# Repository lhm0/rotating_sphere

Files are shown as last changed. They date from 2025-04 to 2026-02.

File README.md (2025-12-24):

# Rotating LED Sphere – RP2040 POV Display
**UPDATE December 24th, 2025**
I have made a change to the header of the motor in order to make the connection to the sphere stronger and long term stable.

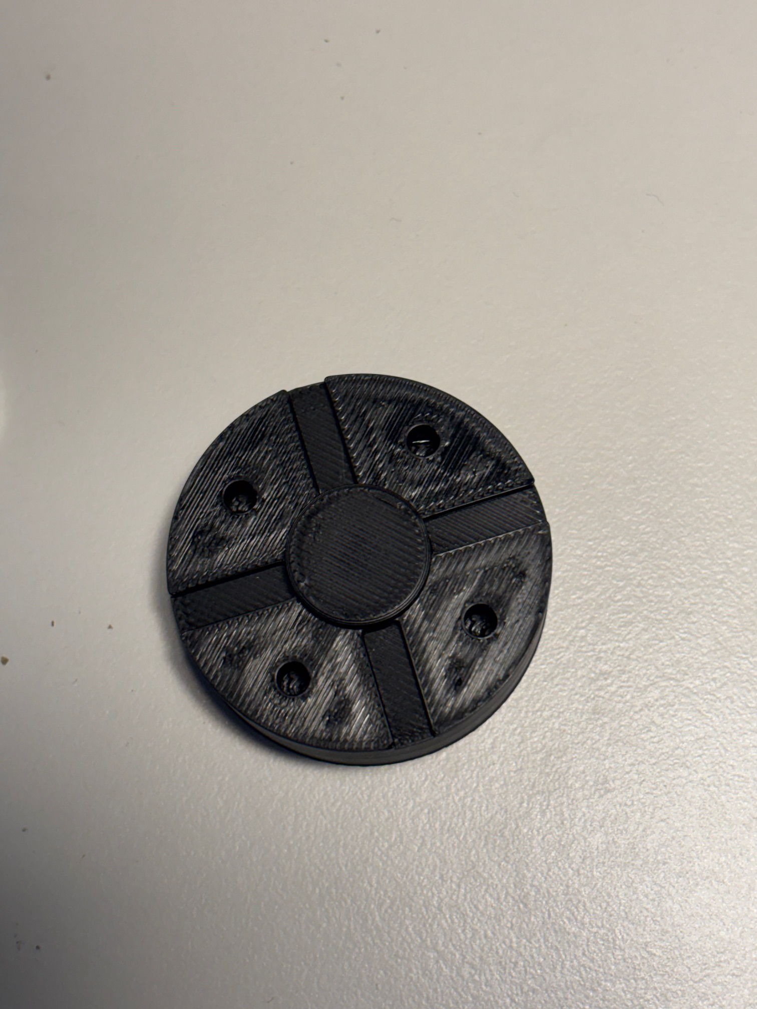
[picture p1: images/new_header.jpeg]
New header without alignment screws


However, alignment of the rotor now is done by placing washers between header and pcb, if necessary.

Furthermore, I have added a file "print_instructions.pdf" in the /mechanics subfolder, with slicer images of the parts that need nut inlays.

**UPDATE August 29th, 2025**
There are two push switches on the power supply pcb, that control the speed of the motor. The "speed" button is used to increase the motor speed step by step. Once the maximum speed is reached, it jumps back to zero. The "off" button turns the motor off.

However, The buttons were previously positioned at the same height as the power supply circuit board, very close to the rotating sphere assembly. To reduce the risk of injury, I have moved the buttons to the center of the power supply housing in the latest version of the housing. The movement of the two buttons is transferred to the switches on the circuit board purely mechanically, so that no modification of the circuit board is necessary.

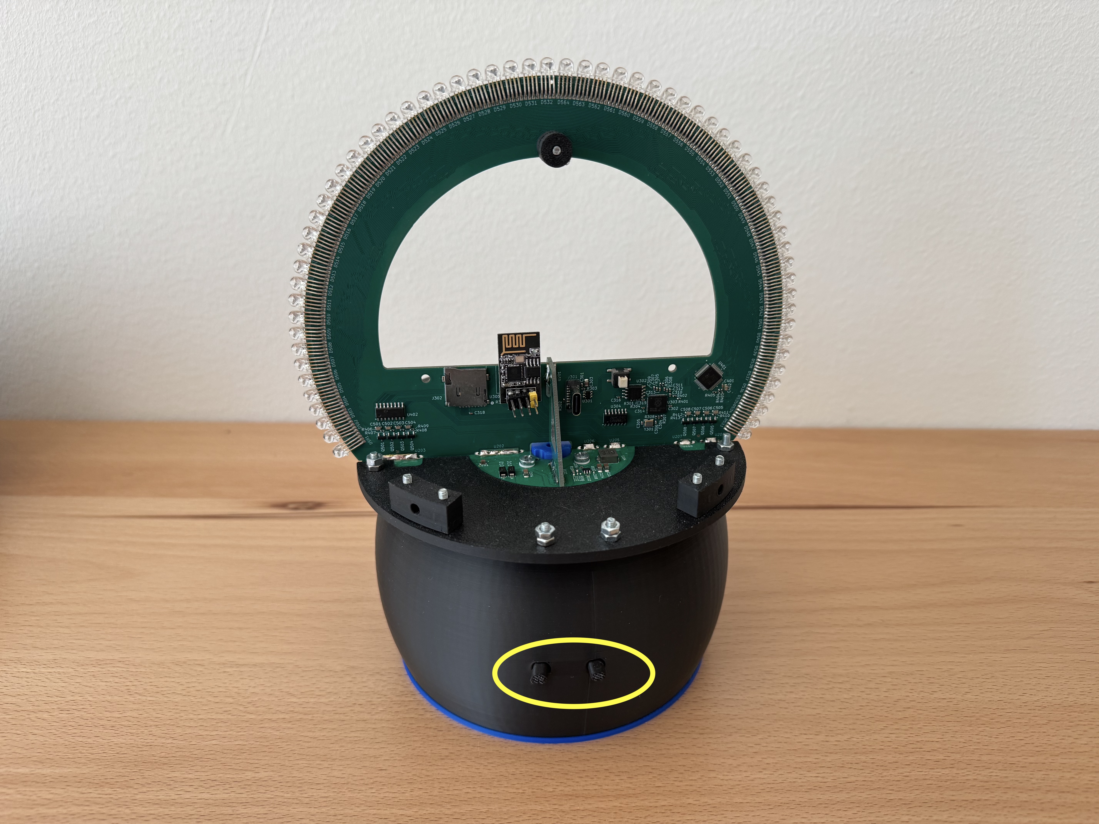
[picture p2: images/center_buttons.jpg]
The two buttons are in the center of the base, now.

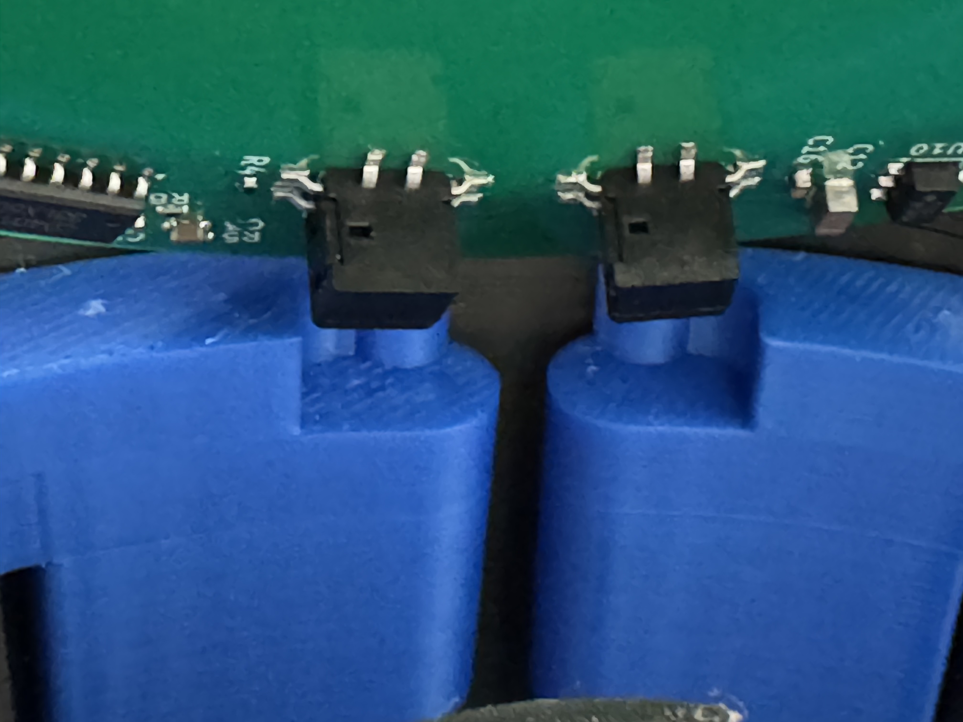
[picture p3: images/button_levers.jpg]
Two levers link the buttons with the switches.


**UPDATE May 29th, 2025**

In the meantime I had the new power supply board built and could test it the last couple of days. **It works fine as expected.** 

Power is now supplied from a **standard USB-C power supply** with power delivery ("PD") function via an off-the-shelf USB-C cable. I am using the Apple power supply of my MacBook. The CH224k for controlling the voltage setting works extremely well. The voltage can be set with a 3 bit dip switch, easily. When set to 15 V, the transmitted energy to the LED board is sufficient even for the highest brightness setting. Of course, the losses of the wireless power transmission show up as heat, but the temperature looks reasonable to me.

The motor power supply has a **stronger step-down converter chip** now (TPS54302 instead of TPS54202 in the old design). The circuit allows for up to 3A of motor current. Furthermore, I introduced a button control logic for setting the motor speed in 5 steps. There are two buttons: increase speed, and OFF. This eliminates the potentiometer and the on/off switch in the old design.

Finally, I **increased the diameter of the circular hole in the middle of the pcb**, which allows for a significantly larger and stronger motor to LED-board connection. The tray disk has a larger diameter now. The 4 holes in the secondary coil pcb are now being used for securing the LED assembly to the motor.

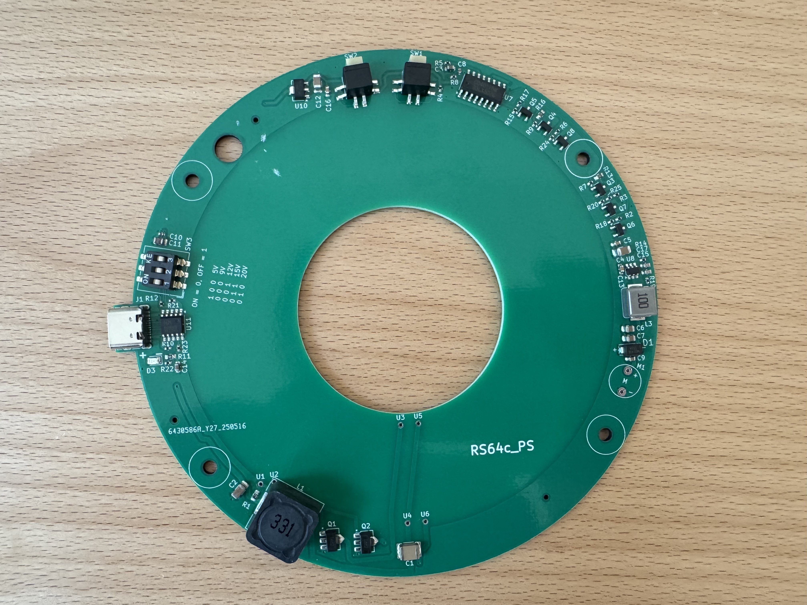
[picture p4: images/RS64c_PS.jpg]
USB-C power supply for the rotating sphere


In order to fit the new pcb, I had to modify the housing. Please find the related files in this repository.

**UPDATE May 10th, 2025**
I am currently working on an update of the power supply. The idea is to replace the 12V power plug with an USB-C PD (power delivery) power supply. I am interested in the CH224K, which manages the voltage negotiation with the USB PD. This would allow us to use a standard USB-C charger (probably about 25 - 35 W) for supplying the device. USB power delivery can provide 5, 9, 12, 15, or 20V. This is exactly the range needed for the rotating sphere. At the same time I will replace the motor power regulator with a stronger one. Currently, the motor current cannot go above 2A, which is just barely sufficient.

If you are interested, stay tuned. However, it will definitely take 4 weeks, probably more, to get it done.

**UPDATE April 30th, 2025**
@randybeever5206 made me aware (**thank you!**), that the value of R403, R404, and R405 on the main display board should be 270 Ohm according to the schematic, but the properties field and the corresponding line in the production file refers to a 1k resistor instead. Let me explain:

1. these three resistors set the forward peak current of the LEDs. 1k corresponds to 20 mA, 270 Ohms corresponds to 75 mA. 
2. I had copied this part of the schematic from an earlier project, changed the value but missed to change the component in the production data. As a result, I worked with 20mA, although I thought it was 75.
3. I have changed the resistors in my unit from 1k to 270 Ohm in the meantime (what a pain: these are 0402 resistors!). Yes, it is significantly brighter. For some reason, colors look even more saturated, now. The color animation, which can be seen in the video, looks stunning.
4. However, higher brightness means higher power consumption. If you supply the device with a 12 V power plug (12V, 2A), you can not run it at 100% brightness. I found that the processor crashes, when you go too high. This is obviously a voltage breakdown.
5. Fortunately, I designed the power supply such that it can be operated with up to 24V. When you run the sphere with 17V or above, you can go up to 100% brightness.
6. Here is my recommendation: use 270 Ohm resistors. If you run the device at 12V, you need to reduce the brightness setting, so that the device works flawlessly. If you want more, you need a power supply with more than 17V, 2 or better 3 A (consumption depends on motor speed).
7. I have updated the schematic and the production file in the meantime.

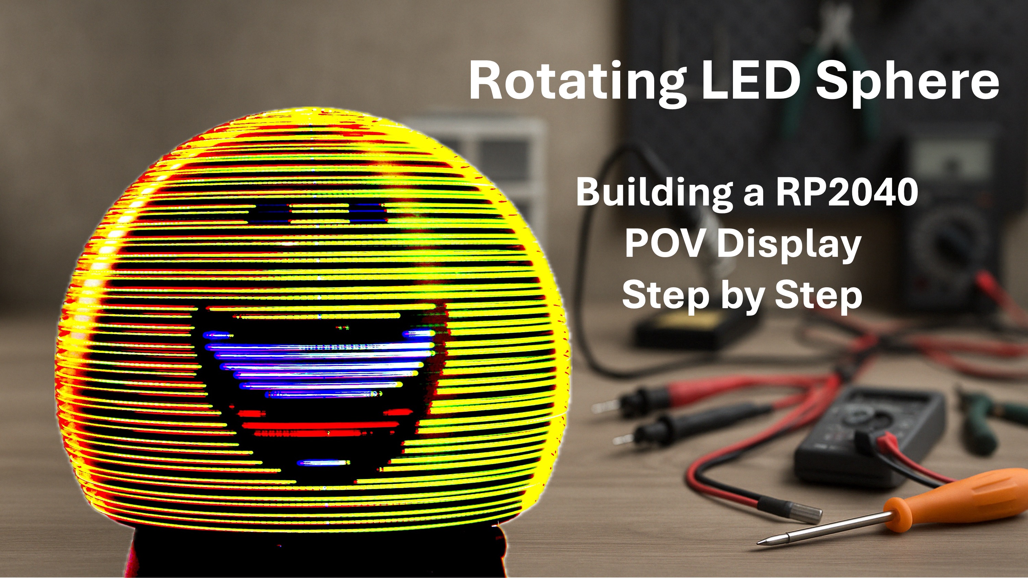
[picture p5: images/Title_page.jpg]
Rotating LED Sphere


## 📌 Project Overview

This project describes the design and construction of a **rotating LED sphere** using the **persistence-of-vision (POV)** principle.  
The device is controlled by a **Raspberry Pi RP2040 microcontroller** and is capable of displaying **videos, animated GIFs**, and **static images** on a spherical 3D surface.

The project is inspired by the Las Vegas Sphere – scaled down to desktop size, but packed with smart engineering like **wireless power transmission**, **real-time SDIO video streaming**, and **web-based remote control**.

All hardware, software, PCB layouts and 3D printable parts are **open source** and included in this repository.

---

## ✨ Features

- 🟡 64 RGB LEDs arranged to form a 170 mm spherical POV display  
- 📊 Display resolution: **64 × 256 pixels** **(corrected: it is NOT 128 x 256)**  
- 🎞️ Supports **.rs64** video/image format (GIFs, animations, stills)  
- 💾 Real-time video streaming from **SD card via SDIO (4-bit)**  
- ⚙️ Driven by an **RP2040** using fast **PIO-based multiplexing**  
- 🌐 Optional **ESP01s** module creates a web-based control interface  
- 🔌 **Wireless power** using a Royer converter – no slip rings needed  
- 🧠 Designed to be **easy to build**, with a minimal part count  
- 🧰 All files included: **KiCad PCB**, **PlatformIO code**, **3D models**

---

## 🧱 System Components

- **RP2040 microcontroller** (via Raspberry Pi Pico or custom PCB)  
- **ESP01s (optional)** for Wi-Fi control and web interface  
- **SD card slot** (with high-speed SDIO interface)  
- **24-bit shift register** and **MOSFETs** for LED driving  
- **3D-printed mechanical components** (rotor, housing, mounts)  
- **Wireless power transmission** with printed transmitter/receiver coils  
- **Hall sensor** for rotation angle synchronization  
- **Custom `.rs64` video format** with 8 brightness levels via PWM

---

## 🛠️ How to Build

The build process is documented in a [step-by-step video tutorial](https://www.youtube.com/yourvideolink), covering:

1. Mechanical design & 3D printing  
2. Rotor balancing and alignment  
3. Soldering the LED matrix  
4. Power & wireless energy transmission  
5. Programming the RP2040 and ESP01s  
6. Creating `.rs64` files from GIFs and videos  
7. Using the web interface

For detailed instructions, see the [`docs/`](./docs) folder.

---

## 📜 License

This project is licensed under the **Creative Commons BY-NC-SA 4.0** license.  
You are free to **use, adapt, and share** this work for **non-commercial** purposes,  
as long as you give proper credit and share your work under the same terms.

> ✏️ Especially welcomed: use in education, maker communities, and open-source development!

---

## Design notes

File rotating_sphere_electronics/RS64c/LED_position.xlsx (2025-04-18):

r_LED | 62 |  | r_Q | 57.5
U_LED | 389.557489
LED_width | 2.08
nr | Bogen | alpha | alpha(Grad) | x | y |  |  | Q | Bogen_LED
501 | 131.56 | 2.121935484 | 121.5779476 | -52.81956986 | 32.46679903 | 31.57794762 |  | 501 | 126.36 | 2.038064516 | -51.33612417 | 25.90081766 | 116.7724951
502 | 129.48 | 2.088387097 | 119.6557666 | -53.87885303 | 30.67685115 | 29.65576663
503 | 127.4 | 2.05483871 | 117.7335856 | -54.87750154 | 28.85237989 | 27.73358564
504 | 125.32 | 2.021290323 | 115.8114047 | -55.81439152 | 26.99543848 | 25.81140465
505 | 123.24 | 1.987741935 | 113.8892237 | -56.68846863 | 25.10811671 | 23.88922366 |  | C501 | 122.2 | 1.970967742 | -52.95716813 | 22.40063267 | 112.9281332
506 | 121.16 | 1.954193548 | 111.9670427 | -57.49874916 | 23.19253855 | 21.96704267
507 | 119.08 | 1.920645161 | 110.0448617 | -58.24432126 | 21.25085977 | 20.04486168
508 | 117 | 1.887096774 | 108.1226807 | -58.92434585 | 19.28526551 | 18.12268069
509 | 114.92 | 1.853548387 | 106.2004997 | -59.53805765 | 17.29796783 | 16.2004997 |  | 502 | 109.72 | 1.769677419 | -56.36657477 | 11.36042467 | 101.3950472
510 | 112.84 | 1.82 | 104.2783187 | -60.08476599 | 15.29120322 | 14.27831871
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

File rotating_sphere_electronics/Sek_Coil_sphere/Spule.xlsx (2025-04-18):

 | M | M | S | S | R | E | alpha | x | y
1 | 0 | 0.45 | 0 | 46 | 45.55 | -45.1 | 65 | 41.2823197 | 19.70026182
1 |  | -0.45 |  | -45.1 | -44.65 | 44.2
2 |  | 0.45 |  | 44.2 | 43.75 | -43.3
2 |  | -0.45 |  | -43.3 | -42.85 | 42.4
3 |  | 0.45 |  | 42.4 | 41.95 | -41.5
3 |  | -0.45 |  | -41.5 | -41.05 | 40.6
4 |  | 0.45 |  | 40.6 | 40.15 | -39.7
4 |  | -0.45 |  | -39.7 | -39.25 | 38.8
5 |  | 0.45 |  | 38.8 | 38.35 | -37.9
5 |  | -0.45 |  | -37.9 | -37.45 | 37
6 |  | 0.45 |  | 37 | 36.55 | -36.1
6 |  | -0.45 |  | -36.1 | -35.65 | 35.2
7 |  | 0.45 |  | 35.2 | 34.75 | -34.3
7 |  | -0.45 |  | -34.3 | -33.85 | 33.4
8 |  | 0.45 |  | 33.4 | 32.95 | -32.5
8 |  | -0.45 |  | -32.5 | -32.05 | 31.6
9 |  | 0.45 |  | 31.6 | 31.15 | -30.7
9 |  | -0.45 |  | -30.7 | -30.25 | 29.8
10 |  | 0.45 |  | 29.8 | 29.35 | -28.9
10 |  | -0.45 |  | -28.9 | -28.45 | 28
11 |  | 0.45 |  | 28 | 27.55 | -27.1
11 |  | -0.45 |  | -27.1 | -26.65 | 26.2
 |  | 0.45 |  | 26.2 | 25.75 | -25.3
 |  | -0.45 |  | -25.3 | -24.85 | 24.4
 |  | 0.45 |  | 24.4 | 23.95 | -23.5
 |  | -0.45 |  | -23.5 | -23.05 | 22.6
 |  | 0.45 |  | 22.6 | 22.15 | -21.7
 |  | -0.45 |  | -21.7 | -21.25 | 20.8

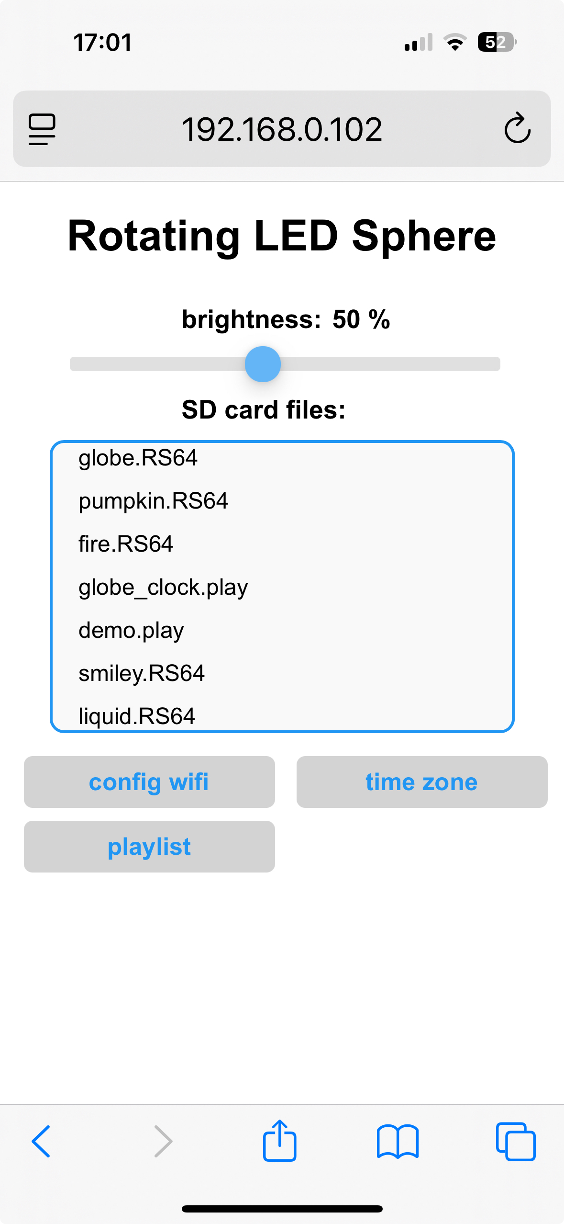
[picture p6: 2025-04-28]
images/webinterface.jpeg

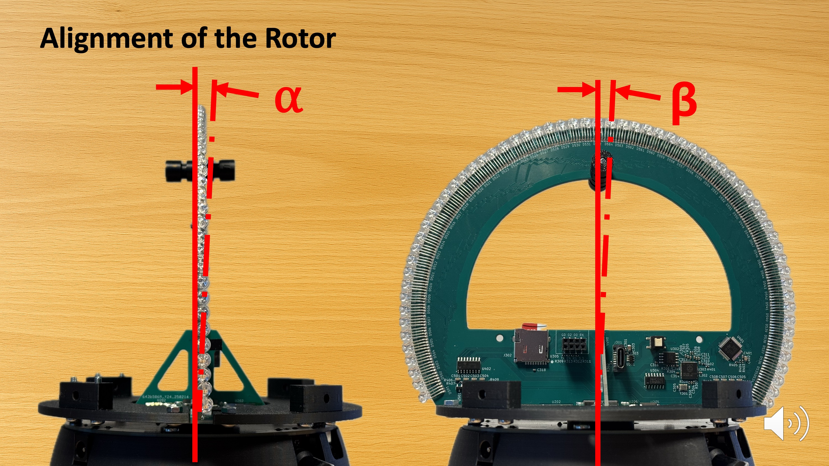
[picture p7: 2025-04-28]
images/alignment1.jpg

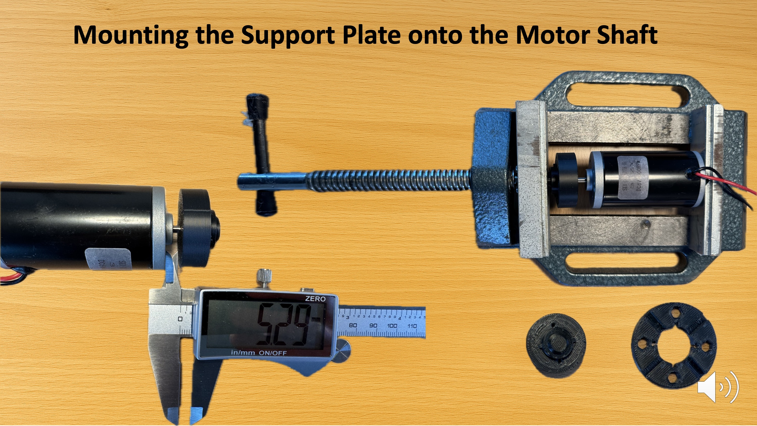
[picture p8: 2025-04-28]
images/mounting_support_plate.jpg

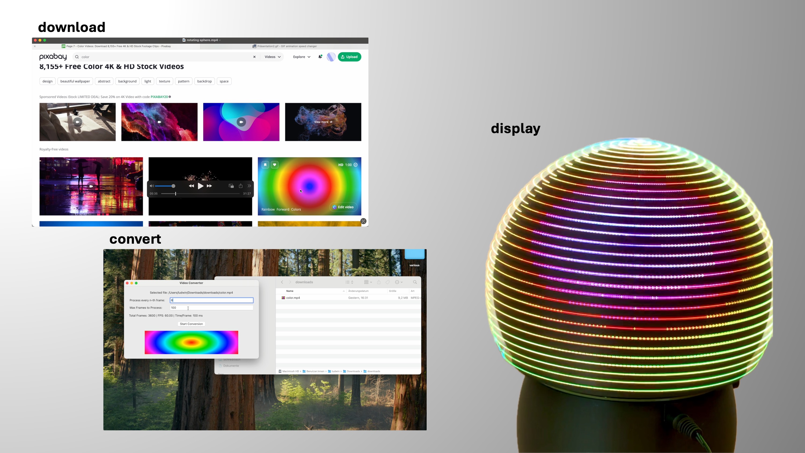
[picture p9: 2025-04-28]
images/conversion.jpg

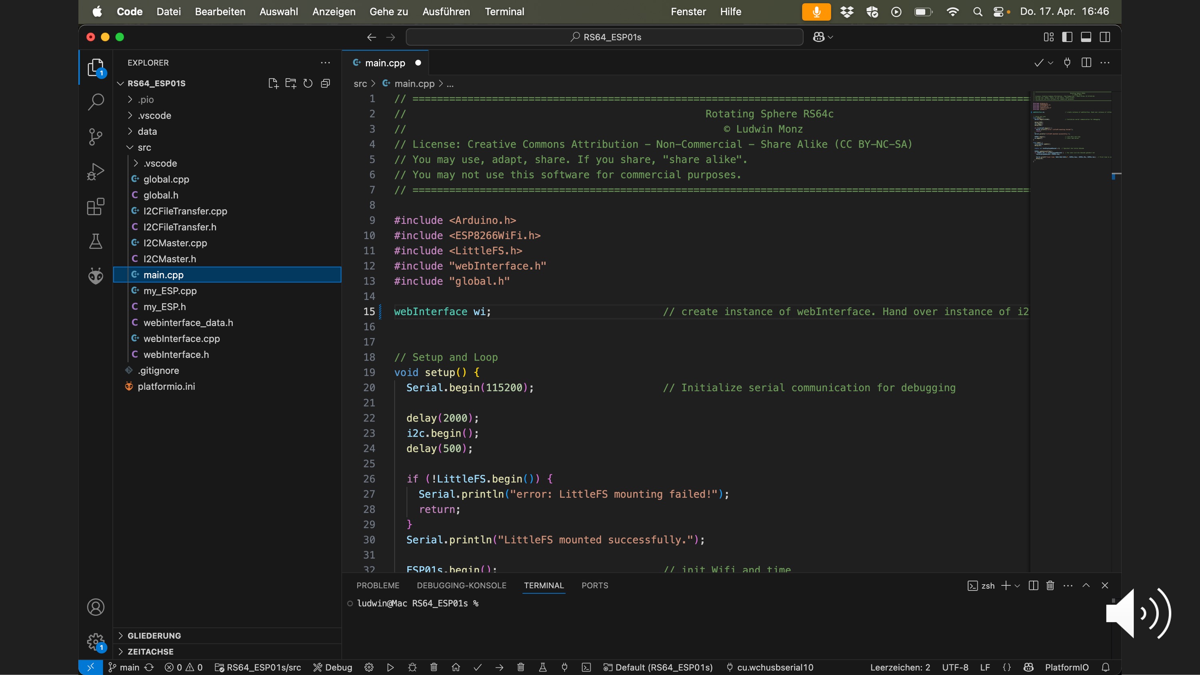
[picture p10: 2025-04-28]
images/software4.jpg

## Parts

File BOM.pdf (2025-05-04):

# BOM Rotating Sphere

number of
units | item | source | link
1 | 1 assembled PCB "RS64c", LED & microcontroller unit | JLCPCB or any other PCB manufacturer. I used the JLCPCB
| | soldering and assembly service. All data for ordering is available
| | on GitHub | https://jlcpcb.com
2 | 1 assembled power supply PCB "RD56c_PS_V1" | JLCPCB or any other PCB manufacturer. I used the JLCPCB
| | soldering and assembly service. All data for ordering is available
| | on GitHub | https://jlcpcb.com
3 | 1 assembled PCB "Sek_coil_sphere" | JLCPCB or any other PCB manufacturer. I used the JLCPCB
| | soldering and assembly service. All data for ordering is available
| | on GitHub | https://jlcpcb.com
4 | 1 PCB "RS64c_holder" | JLCPCB or any other PCB manufacturer | https://jlcpcb.com
5 | 64 STRAWHAT LED 4,8MM RGB (4-PIN) WEDRGB03-CM | www.led1.de | https://www.led1.de/shop/led-rainbow-rgb-ultrahell/48mm-
| | | rgb/strawhat-led-48mm-rgb-4-pin-wedrgb03-cm.html
6 | 1 ESP01s. Make sure to by the "S" version (ESP01S) which has larger memory Amazon, ebay, others
7 various | 3D printed plastic parts | DIY, all STL and design files on GitHub
8 | 1 DC motor 31ZY, 6V, 4000rpm | Amazon, ebay, others | https://amzn.eu/d/0FNWCg7

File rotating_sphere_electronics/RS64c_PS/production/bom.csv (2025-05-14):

Designator | Footprint | Quantity | Value | LCSC Part #
C1 | 1812 | 1 | 33nF | C97977
C10 | 0402 | 1 | 100nF | C307331
C11 | 0805 | 1 | 10µF | C440198
C12 | 1206 | 1 | 10µF | C13585
C13, C16, C5, C9 | 0603 | 4 | 100nF | C14663
C14, C3 | 0603 | 2 | 1µF | C15849
C15 | 0603 | 1 | 47pF | C1671
C17 | 0603 | 1 | 22pF | C1653
C2 | 1206 | 1 | 10µ, 50V | C13585
C4 | 1206 | 1 | 10µF, 50V | C13585
C6, C7 | 0805 | 2 | 22µF | C45783
C8 | 0402 | 1 | 1nF | C1523
D1 | DIOM7959X265N | 1 | SS34 | C8678
D3 | 0805 | 1 | LED | C84256
J1 | USB_C_Receptacle | 1 | USB_C_Receptacle_USB2.0 | C709357
L1 | L_SXN_SMDRI127 | 1 | 330µH | C10152
L3 | L_Bourns_SRP7028A_7.3x6.6mm | 1 | 10µH | C5189958
M1 | motor | 1 | Motor_DC
Q1, Q2 | D882 | 2 | D882 | C9634
Q3, Q4, Q5, Q6, Q7, Q8 | SOT-23 | 6 | BSS138 | C7420339
R1 | 0603 | 1 | 2k2 | C4190
R10, R12, R21, R23, R3 | 0402 | 5 | 10k | C25744
R11, R25 | 0402 | 2 | 1k | C11702
R13 | 0603 | 1 | 56k | C23206
R14, R6 | 0402 | 2 | 100k | C25741
R15, R18, R20, R24, R7, R9 | 0402 | 6 | 47k | C25792
R16 | 0603 | 1 | 30k | C22984
R17 | 0402 | 1 | 20k | C25765
R19 | 0402 | 1 | 49.9 | C25120
R2 | 0402 | 1 | 15k | C25756
R22 | 0603 | 1 | 1k | C21190
R4 | 0402 | 1 | 100R | C25076
R5 | 0402 | 1 | 22k | C25768
R8 | 0402 | 1 | 4k7 | C25900
SW1, SW2 | XKB5858-X-F-75 | 2 | ~ | C780037
SW3 | SW_DIP_SPSTx03_Slide_9.78x9.8mm_W8.61mm_P2.54mm | 1 | SW_DIP_x03 | C7421520
U1, U2, U3, U4, U5, U6 | Pin_2mm | 6 | Pin-Connector
U10 | SOT-89-3 | 1 | HT7550-1-SOT89 | C16106
U11 | SSOP-10-1EP_3.9x4.9mm_P1mm_EP2.1x3.3mm | 1 | CH224K | C970725
U12, U13, U9 | JLC_tooling_hole | 3 | ~
U7 | SOP-16_3.9x9.9mm_P1.27mm | 1 | 4017 | C22390236
U8 | SOT-23-6 | 1 | TPS54302 | C311983

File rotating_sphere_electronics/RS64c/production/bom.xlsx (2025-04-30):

Designator | Footprint | Quantity | Value | LCSC Part #
C301, C302, C304, C307, C308, C310, C312, C313, C314, C315, C316, C318, C401 | 0402 | 13 | 100nF | C307331
C303 | 0805 | 1 | 10µF | C15850
C305, C306 | 0402 | 2 | 27pF | C1557
C309, C311 | 0402 | 2 | 1µF | C52923
C402, C501, C502, C503, C504, C505, C506, C507, C508 | 0603 | 9 | 10µF | C96446
J301 | USB_C_7082A | 1 | USB_C_Receptacle_USB2.0 | C3001289
J302 | microSD_SMD | 1 | Micro_SD_Card | C5155564
Q501, Q502, Q503, Q504, Q505, Q506, Q507, Q508 | SOT-23 | 8 | IRLML6401 | C2835446
R301, R308 | 0402 | 2 | 1k | C11702
R302, R303 | 0402 | 2 | 5k1 | C25905
R305, R306 | 0402 | 2 | 27R | C321419
R307, R309, R311, R312, R313, R401, R402 | 0402 | 7 | 10k | C25744
R403, R404, R405 | 0402 | 3 | 270 | C25099
R406, R407, R408, R409, R410, R411, R412, R413 | 0402 | 8 | 47k | C25792
SW301 | PS-5824SVA-4PN | 1 | SW_Push_Dual | C5155584
U301 | SOT-23-6 | 1 | USBLC6-2SC6 | C2687116
U302 | SOIC-8_5.23x5.23mm_P1.27mm | 1 | W25Q128JVS | C97521
U303 | QFN-56-1EP_7x7mm_P0.4mm_EP3.2x3.2mm | 1 | RP2040 | C2040
U304 | SO-14_3.9x8.65mm_P1.27mm | 1 | 74AHC04 | C86613
U305 | ESP01s_SMD | 1 | ESP01s | C3975149
U401 | TQFP48-EP_STM | 1 | STP24DP05BTR | C157417
U402 | SO-16_3.9x9.9mm_P1.27mm | 1 | 74HCT138 | C352958
Y301 | Crystal_SMD_3225-4Pin_3.2x2.5mm | 1 | 12MHz | C9002

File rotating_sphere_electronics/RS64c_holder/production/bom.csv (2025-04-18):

Designator | Footprint | Quantity | Value | LCSC Part #
U202_2, U202 | edge_contact | 2 | ~

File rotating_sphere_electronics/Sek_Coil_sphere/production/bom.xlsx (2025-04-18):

Designator | Footprint | Quantity | Value | LCSC Part #
C101, C102 | 0805 | 2 | 22µF, 25V | C45783
C103, C104 | 1206 | 2 | 10µF, 50V | C13585
C105, C106, C107, C108, C117 | 0402 | 5 | 100nF | C307331
C109, C112 | 0402 | 2 | 47pF | C1567
C110 | 0402 | 1 | 10pF | C32949
C111 | 0603 | 1 | 30pF | C1658
C113, C114, C115, C116 | 1206 | 4 | 22µF, 25V | C12891
D101, D102, D103, D104 | DIOM7959X265N | 4 | SS34 | C8678
L103, L104 | L_Bourns_SRP7028A_7.3x6.6mm | 2 | 33µH | C177245
R101, R102, R105, R106 | 0402 | 4 | 100k | C25741
R103 | 0402 | 1 | 22k | C25768
R104 | 0603 | 1 | 13k | C22797
R107 | 0402 | 1 | 20k | C25765
U101, U102 | SOT-23-6 | 2 | TPS54202DDC | C191884
U105 | MH253 | 1 | MH253 | C114369

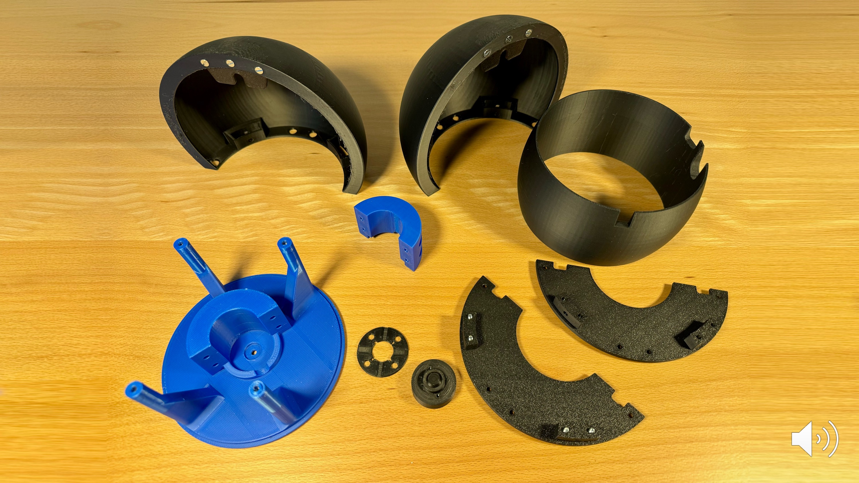
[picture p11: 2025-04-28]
images/plastic_parts.jpg

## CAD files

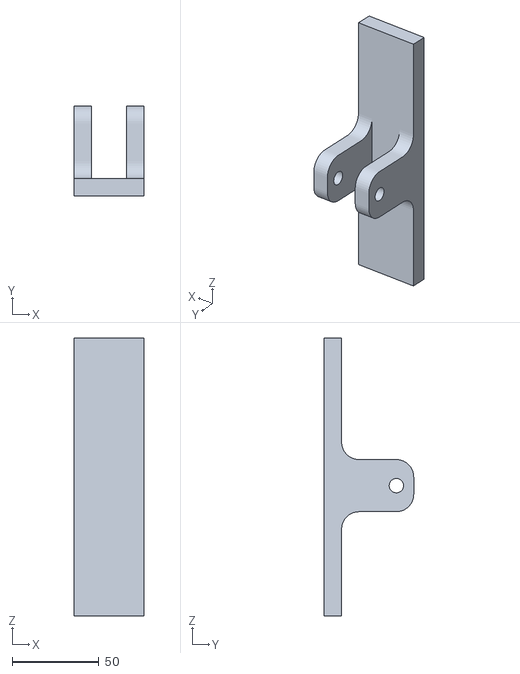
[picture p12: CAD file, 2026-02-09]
rotating_sphere_mechanics/bending_tool/Basis v1.stl
40.0 x 51.5 x 159.9

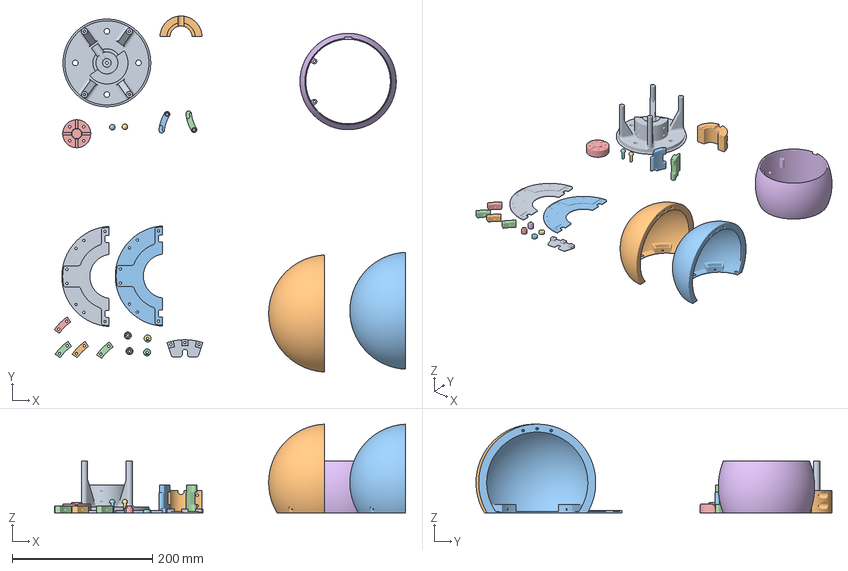
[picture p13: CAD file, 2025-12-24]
rotating_sphere_mechanics/rotating_sphere.3mf
500.3 x 507.0 x 126.3 mm
USB_C_PS2_base.stl
USB_C_PS2_clamp.stl
USB_C_PS2_lever1.stl
USB_C_PS2_lever2.stl
sphere_PS1_USB_C v6.stl
USB_C_PS2_housing.stl
USB_C_PS2_knob.stl x 2
sphere2_base v7.stl x 2
sphere2_block v5.stl x 4
sphere2_disk_back v2.stl x 2
sphere2_dist_back v3.stl x 2
sphere2_top_holder v2.stl
sphere2_dome v14.stl x 2

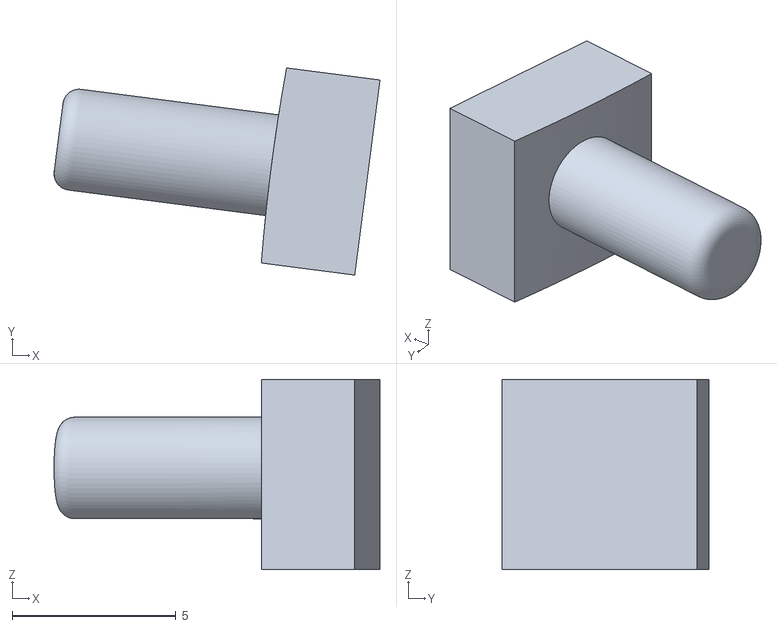
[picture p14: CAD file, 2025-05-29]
rotating_sphere_mechanics/USB_C power supply_ buttons at top/sphere_PS4_knob.stl
9.95 x 6.32 x 5.80

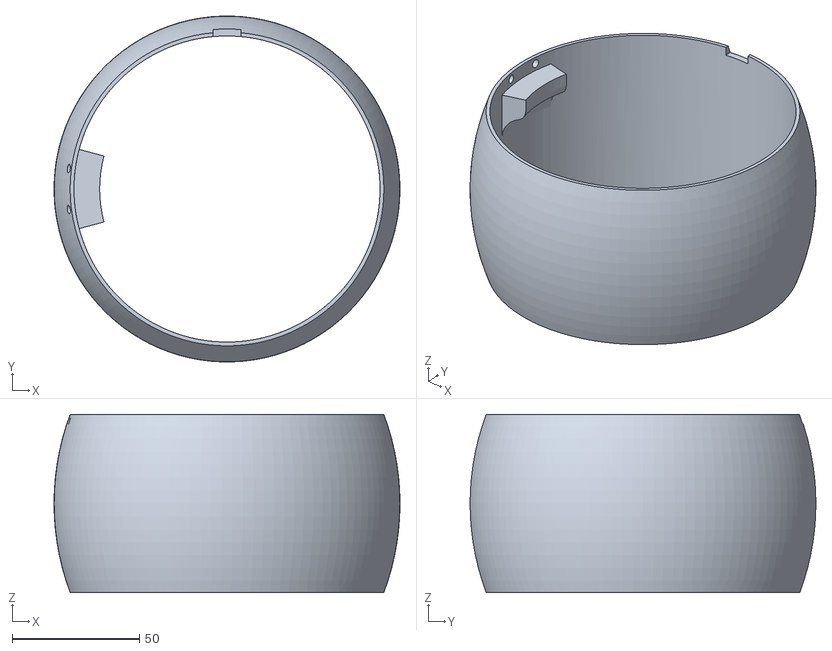
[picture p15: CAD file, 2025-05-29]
rotating_sphere_mechanics/USB_C power supply_ buttons at top/sphere_PS4_USB_C.stl
135.9 x 135.8 x 70.0

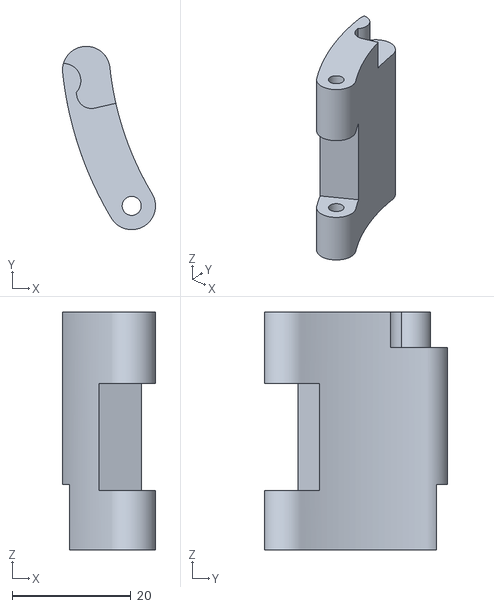
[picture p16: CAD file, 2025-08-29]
rotating_sphere_mechanics/USB_C_PS2_lever1.stl
15.6 x 30.8 x 40.0

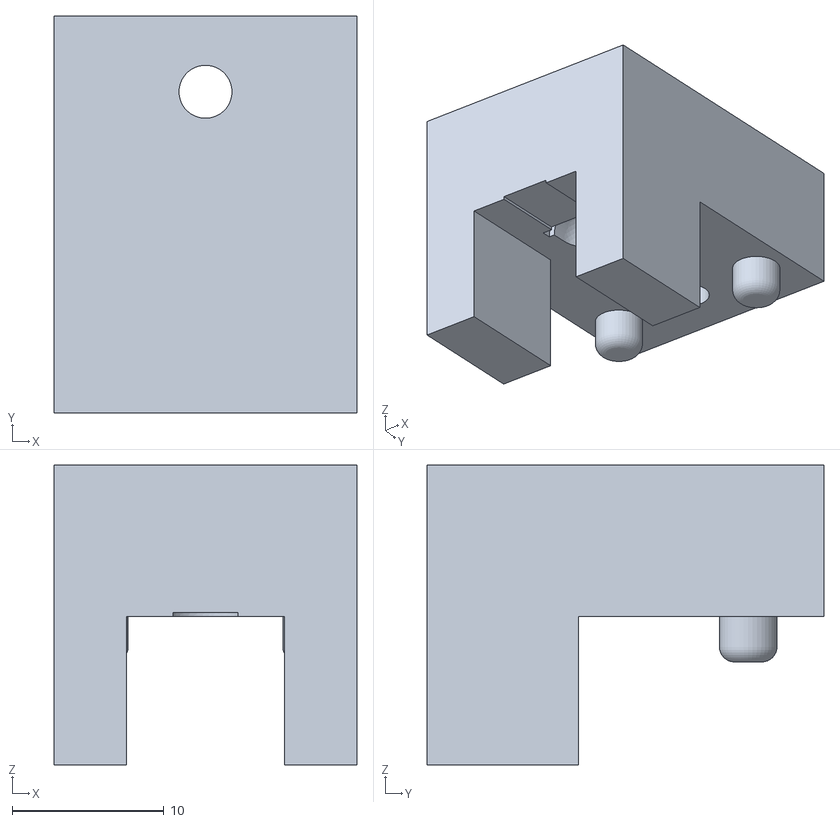
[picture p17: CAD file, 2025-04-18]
rotating_sphere_mechanics/bending_tool/bending_tool_upper_LED v5.stl
20.0 x 26.2 x 19.8

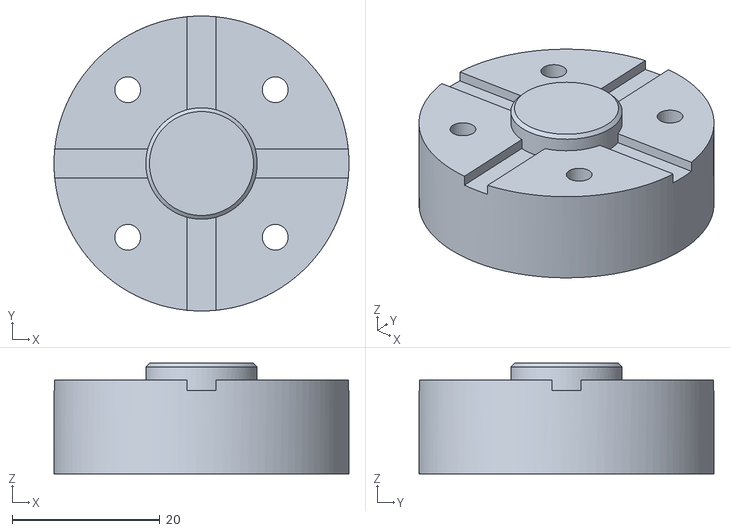
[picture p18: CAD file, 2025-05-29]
rotating_sphere_mechanics/USB_C power supply_ buttons at top/sphere_PS1_USB_C v6.stl
40.0 x 40.0 x 15.0

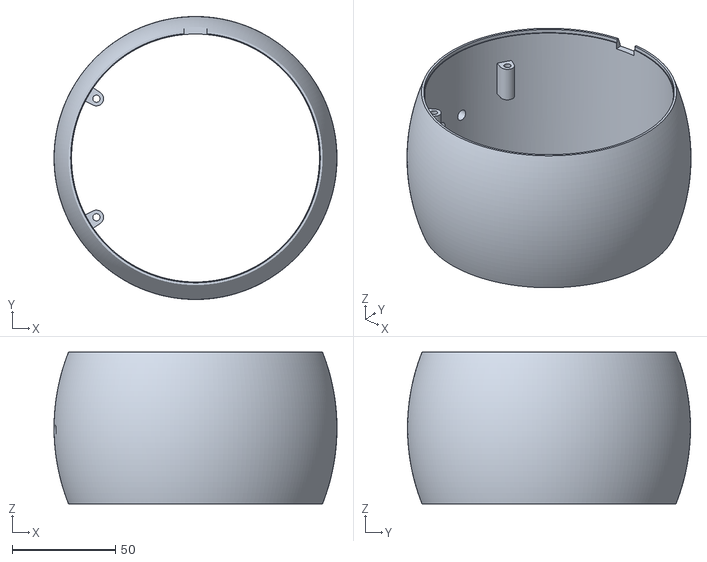
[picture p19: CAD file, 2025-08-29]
rotating_sphere_mechanics/USB_C_PS2_housing.stl
137.2 x 137.2 x 73.6

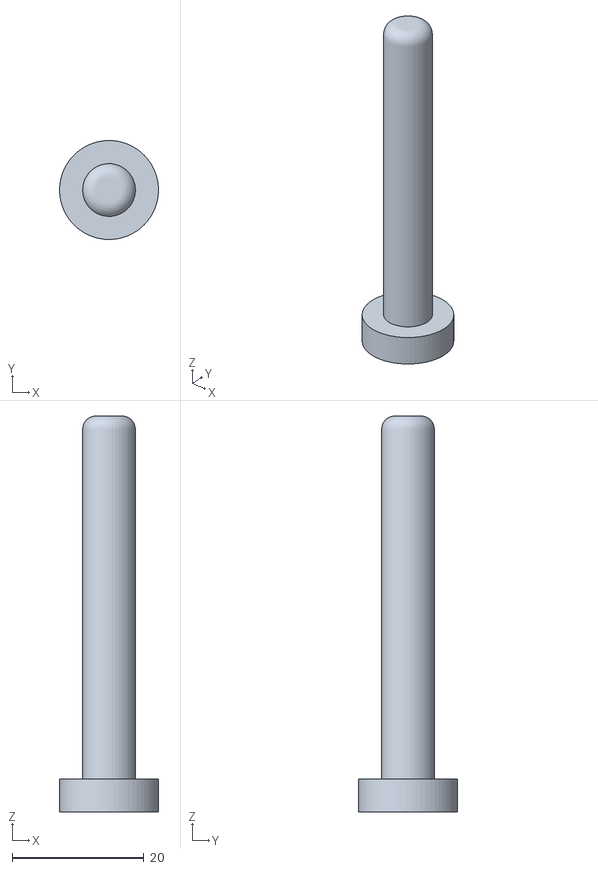
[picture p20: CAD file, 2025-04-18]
rotating_sphere_mechanics/bending_tool/bending_tool_axis v2.stl
15.0 x 15.0 x 60.0

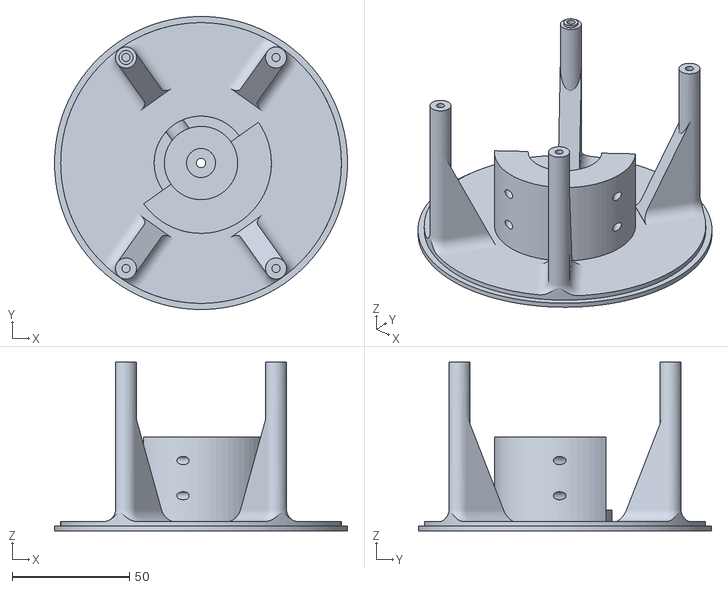
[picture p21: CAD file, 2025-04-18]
rotating_sphere_mechanics/USB_C power supply_ buttons at top/sphere_PS2 v9.stl
125.0 x 125.0 x 72.0

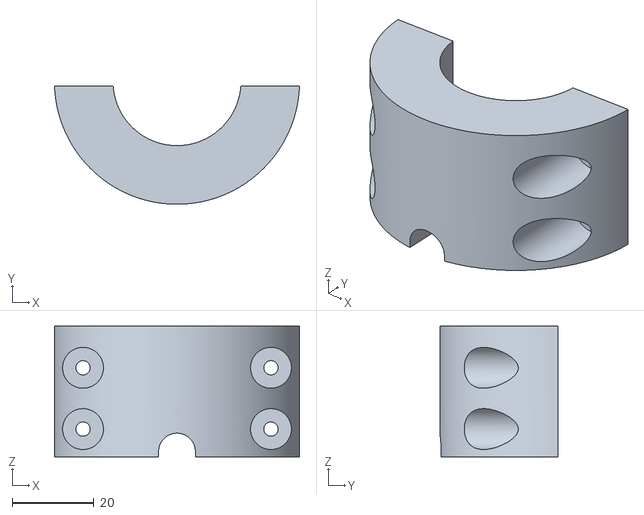
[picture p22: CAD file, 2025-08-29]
rotating_sphere_mechanics/USB_C_PS2_clamp.stl
60.0 x 29.0 x 32.0

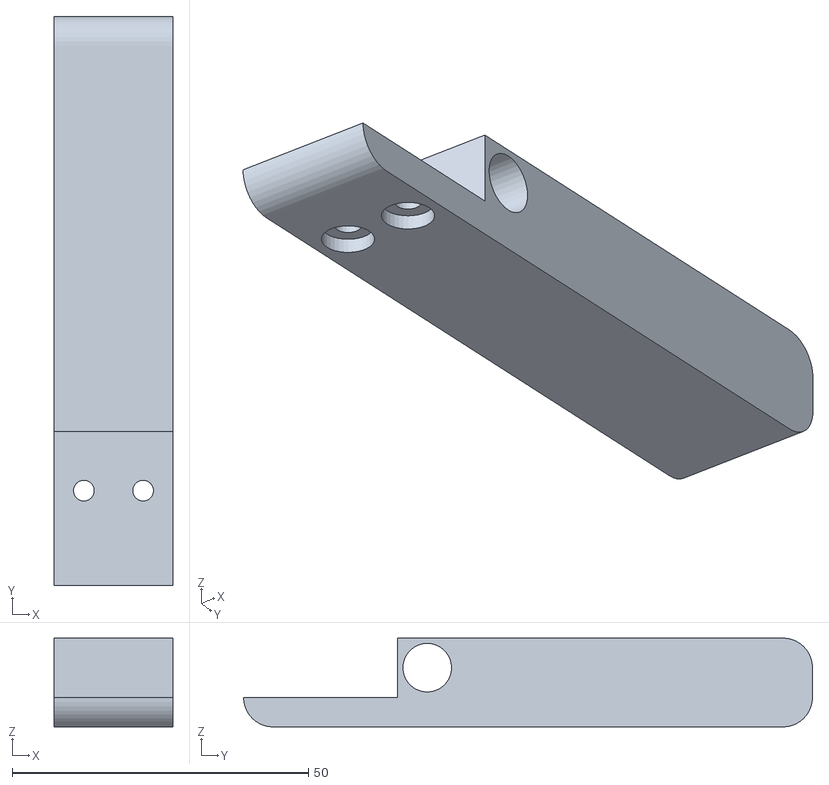
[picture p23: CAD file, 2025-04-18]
rotating_sphere_mechanics/bending_tool/bending_tool_lever v2.stl
20.0 x 96.0 x 15.0

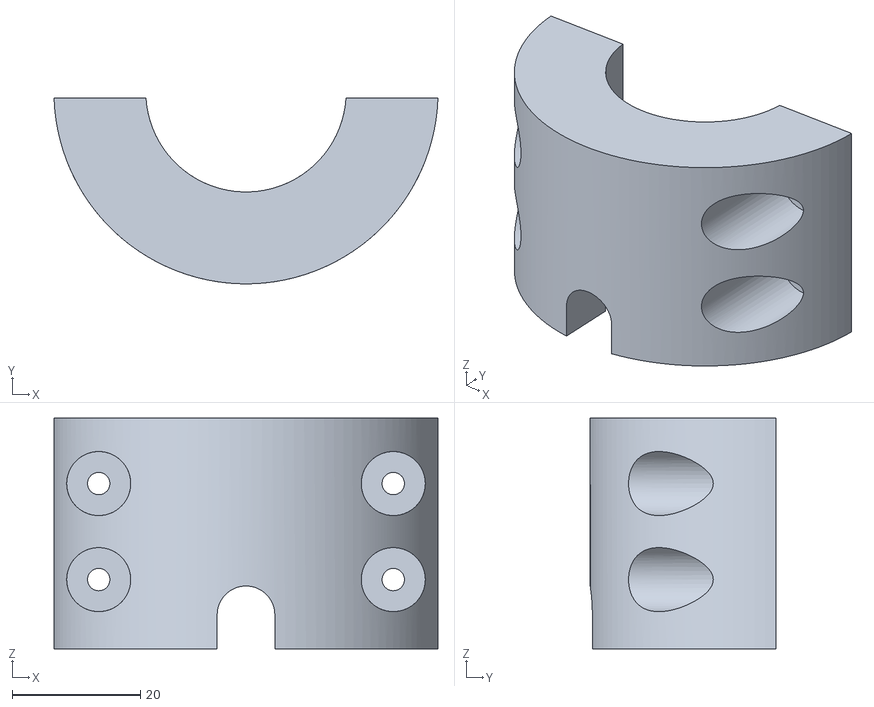
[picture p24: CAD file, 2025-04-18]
rotating_sphere_mechanics/USB_C power supply_ buttons at top/sphere_PS3 v1.stl
60.0 x 29.0 x 36.0

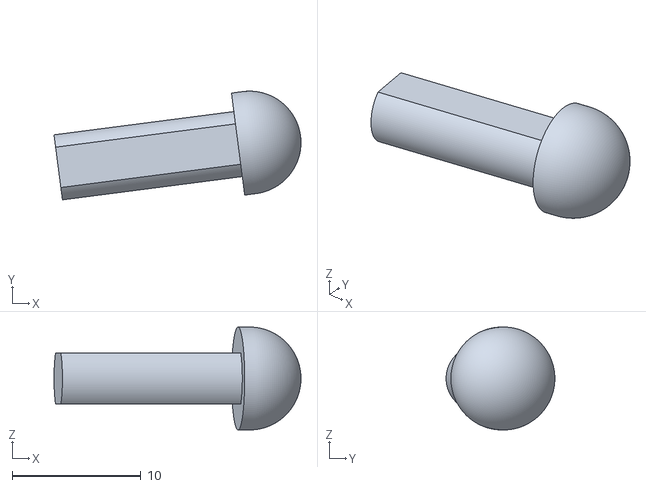
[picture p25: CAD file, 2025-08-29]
rotating_sphere_mechanics/USB_C_PS2_knob.stl
19.2 x 8.45 x 8.00

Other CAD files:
rotating_sphere_mechanics/bending_tool/bending_tool_base v2.stl
rotating_sphere_mechanics/USB_C_PS2_base.stl
rotating_sphere_mechanics/bending_tool/bending_tool_lower_LED v7.stl
rotating_sphere_mechanics/USB_C_PS2_lever2.stl
rotating_sphere_mechanics/USB_C power supply_ buttons at top/sphere_PS1_USB_C v6.f3d
rotating_sphere_mechanics/USB_C power supply_ buttons at top/sphere_PS2 v9.f3d
rotating_sphere_mechanics/USB_C power supply_ buttons at top/sphere_PS3 v1.f3d
rotating_sphere_mechanics/USB_C power supply_ buttons at top/sphere_PS4_USB_C v6.f3d
rotating_sphere_mechanics/USB_C power supply_ buttons at top/sphere_flansh_adapter v4.f3d
rotating_sphere_mechanics/bending_tool/Basis v1.f3d
rotating_sphere_mechanics/bending_tool/bending_tool_axis v2.f3d
rotating_sphere_mechanics/bending_tool/bending_tool_base v2.f3d
rotating_sphere_mechanics/bending_tool/bending_tool_lever v2.f3d
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

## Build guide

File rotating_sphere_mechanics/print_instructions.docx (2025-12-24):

Plate 1:

Pause 1 @ layer40

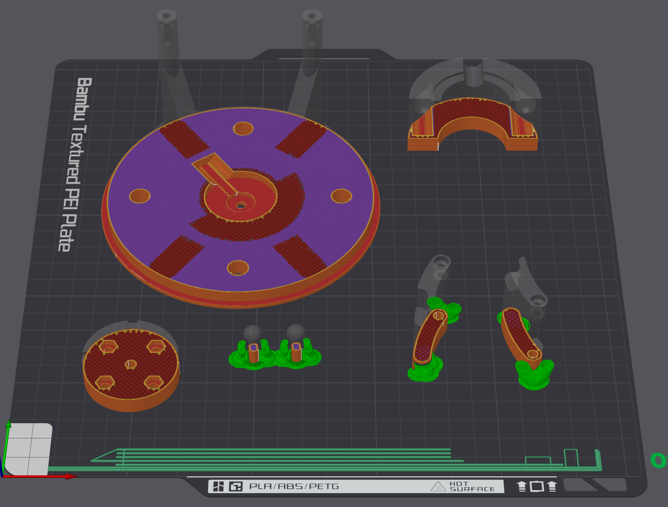
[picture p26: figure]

Pause 2 @ layer 92

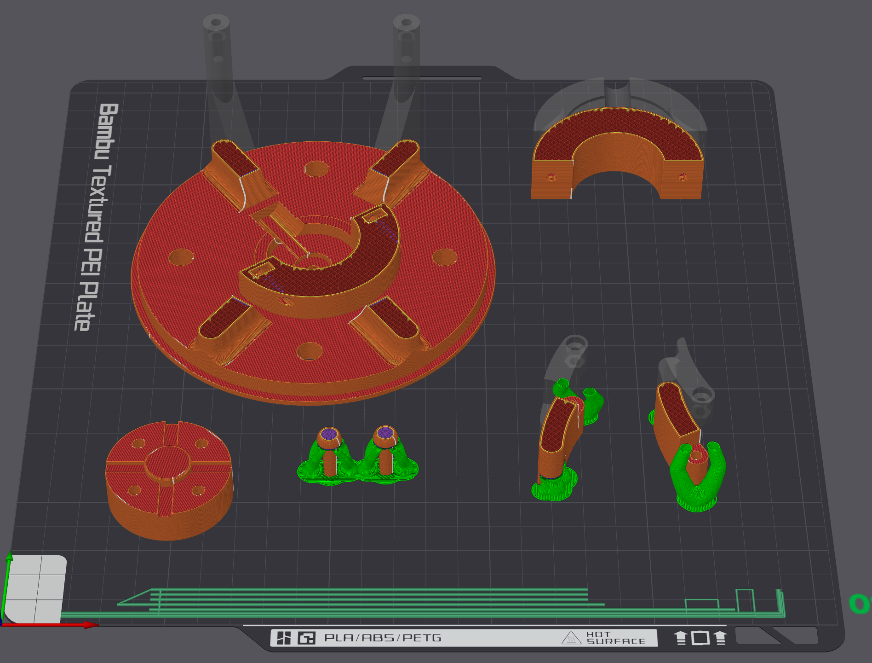
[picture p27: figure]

Pause 3 @ layer 167

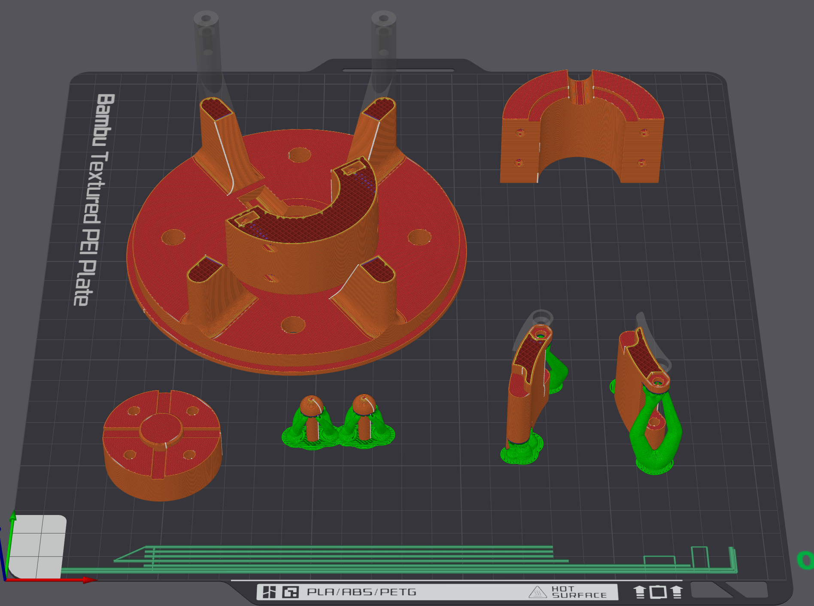
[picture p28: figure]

Pause 4 @ layer 175

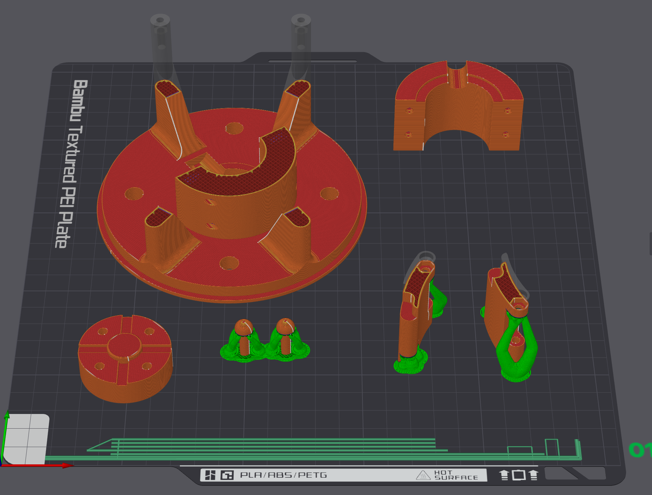
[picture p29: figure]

Pause 5 @ layer 356

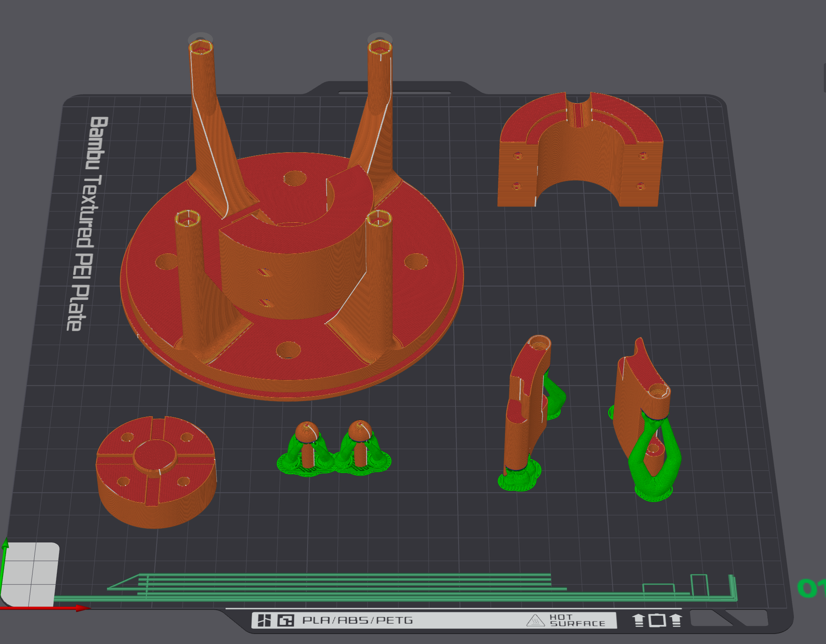
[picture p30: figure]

Plate 3,
Pause 1, layer 25

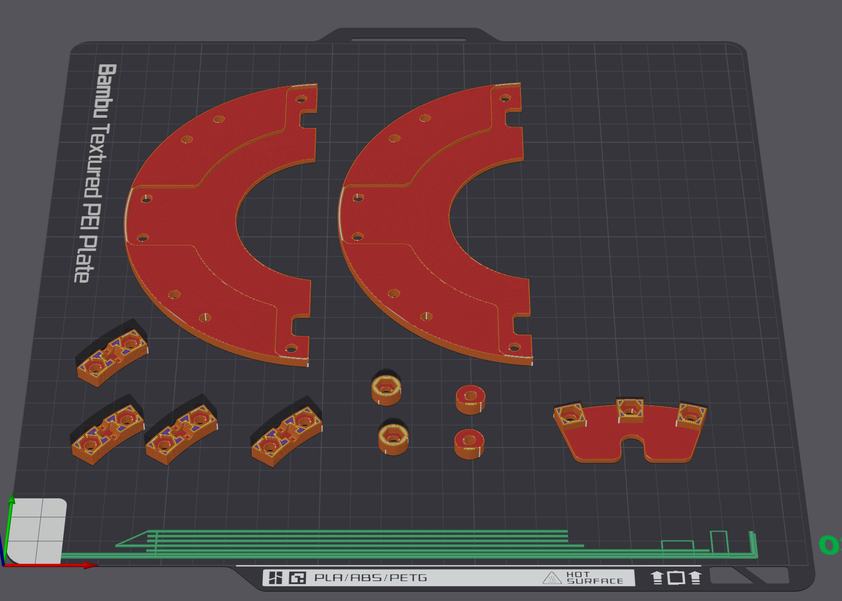
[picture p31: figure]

Pause 2, layer 26

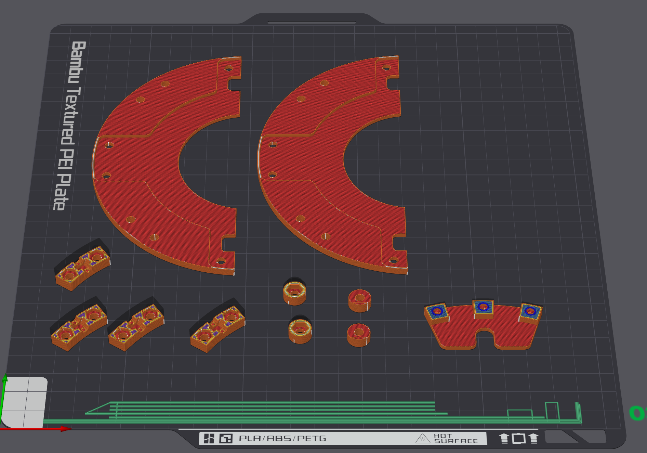
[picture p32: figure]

Pause 3, layer 33

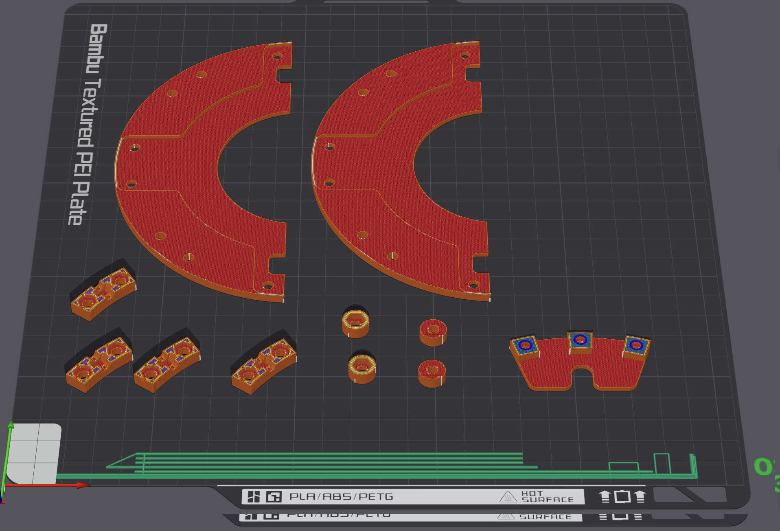
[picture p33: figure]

Pause 4, layer 41

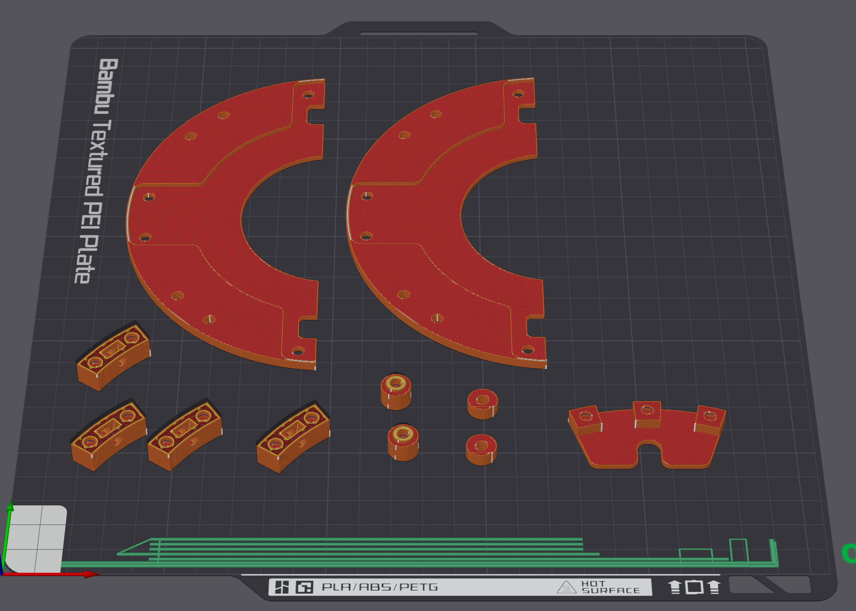
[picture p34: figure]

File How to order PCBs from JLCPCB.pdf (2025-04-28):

## How to order assembled PCBs from JLCPCB

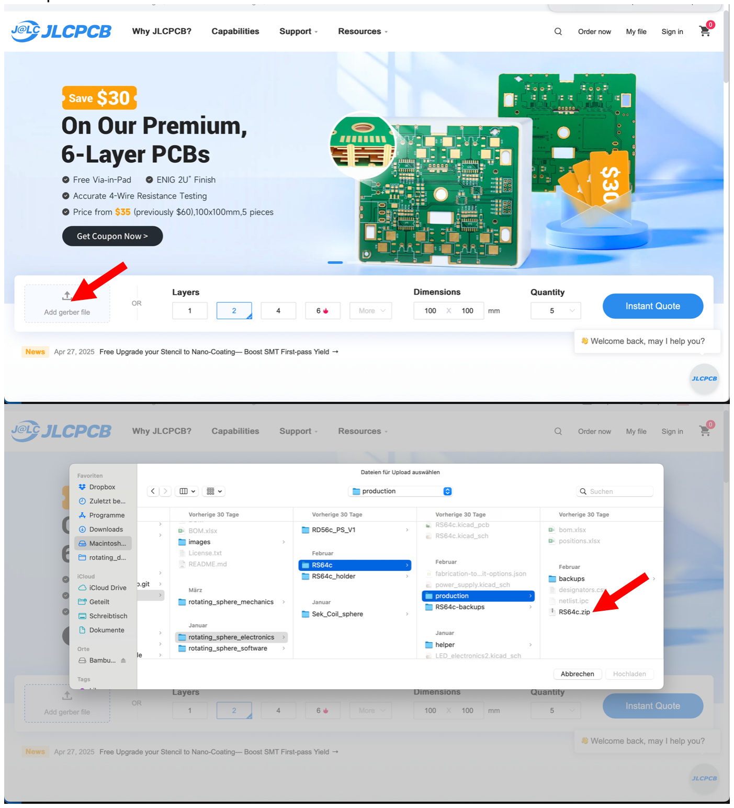
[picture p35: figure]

1. Upload the Gerber ZIP:

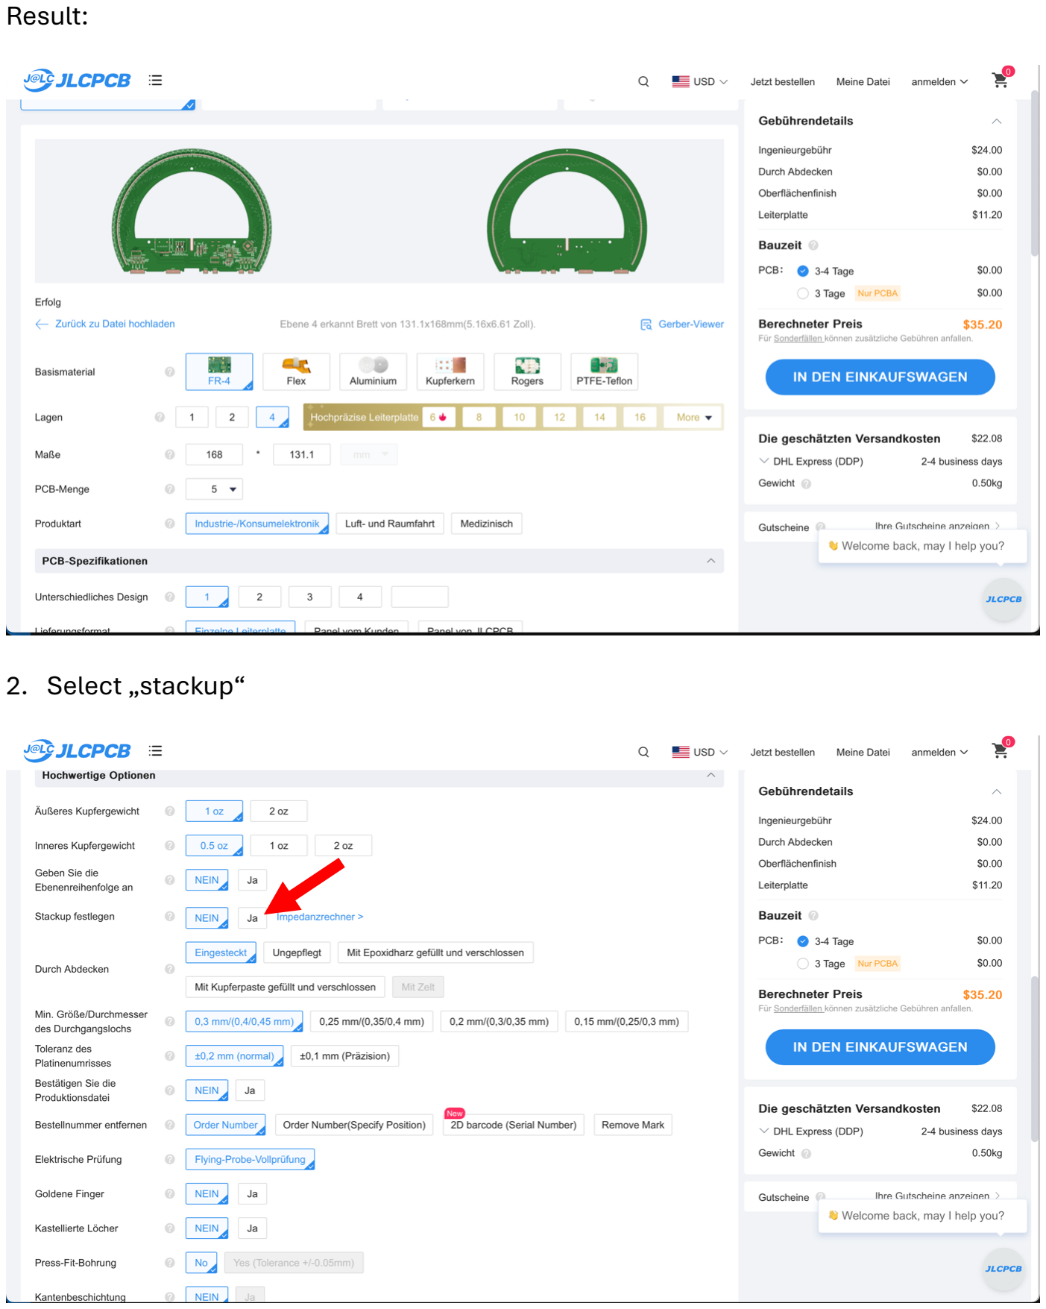
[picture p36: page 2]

Result:

2. Select „stackup“

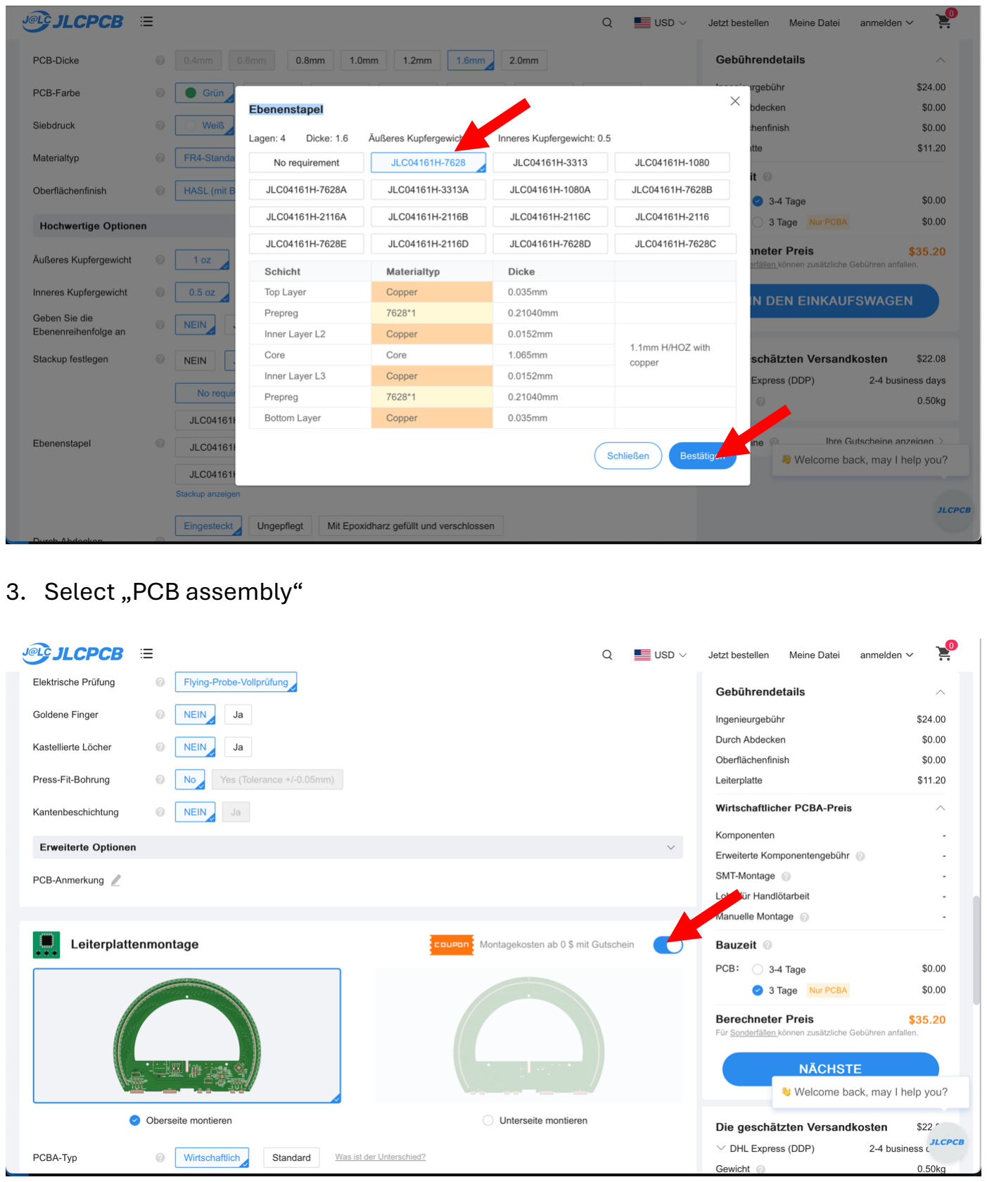
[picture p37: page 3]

3. Select „PCB assembly“

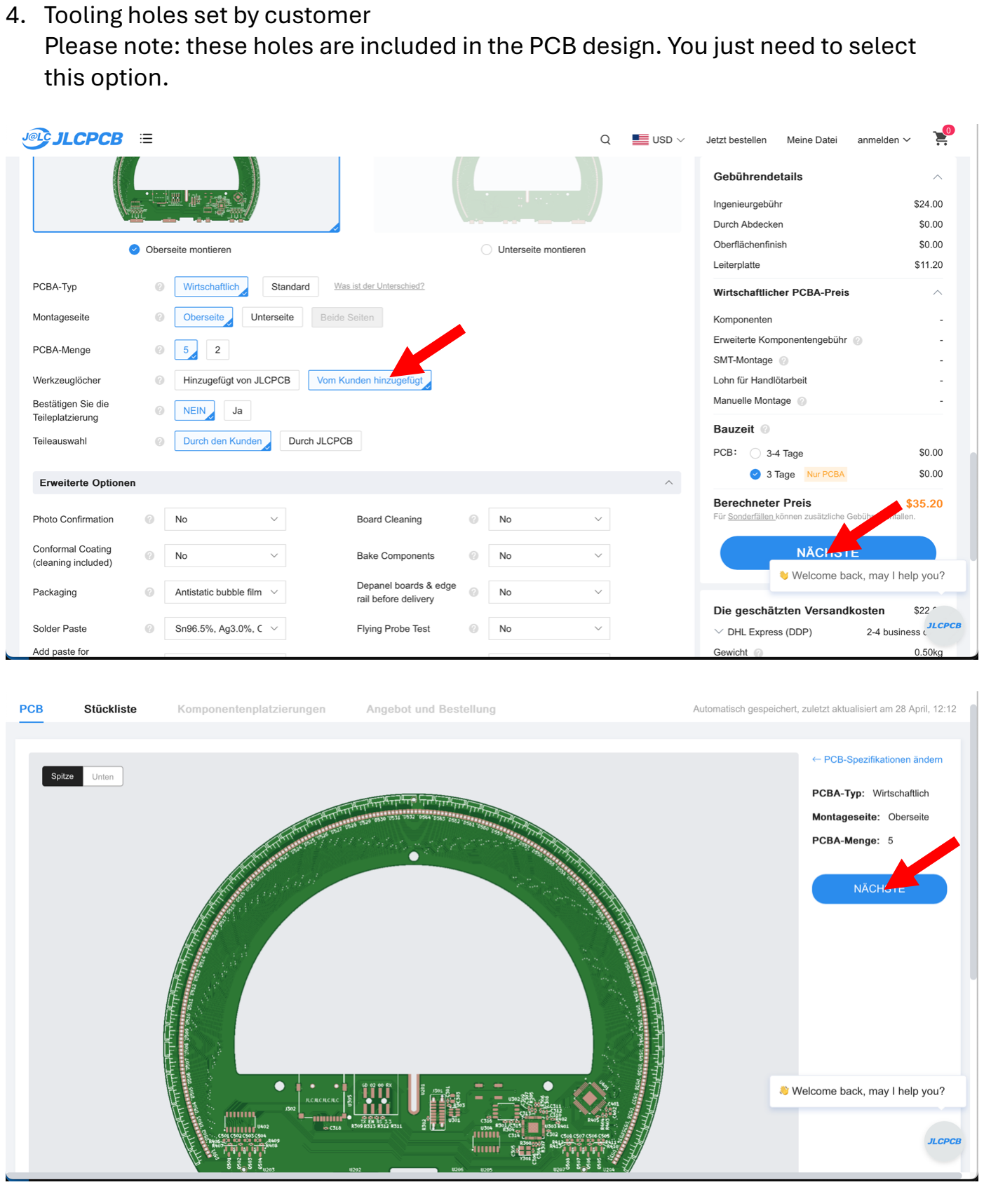
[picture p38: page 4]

4. Tooling holes set by customer
Please note: these holes are included in the PCB design. You just need to select this option.

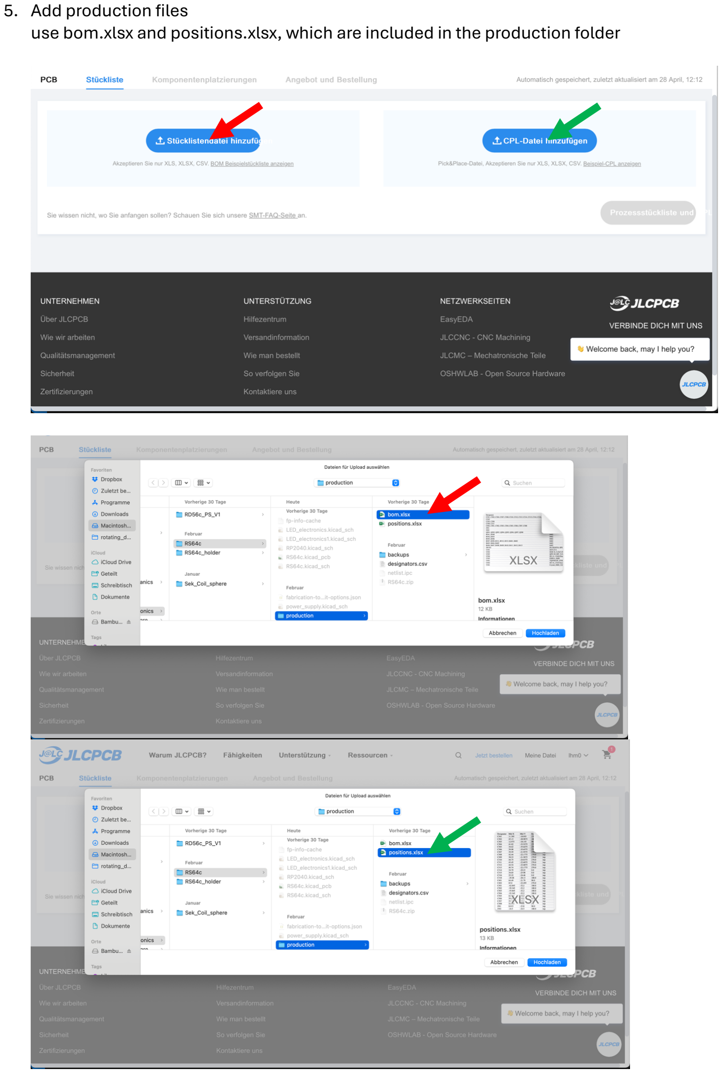
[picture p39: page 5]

5. Add production files
use bom.xlsx and positions.xlsx, which are included in the production folder

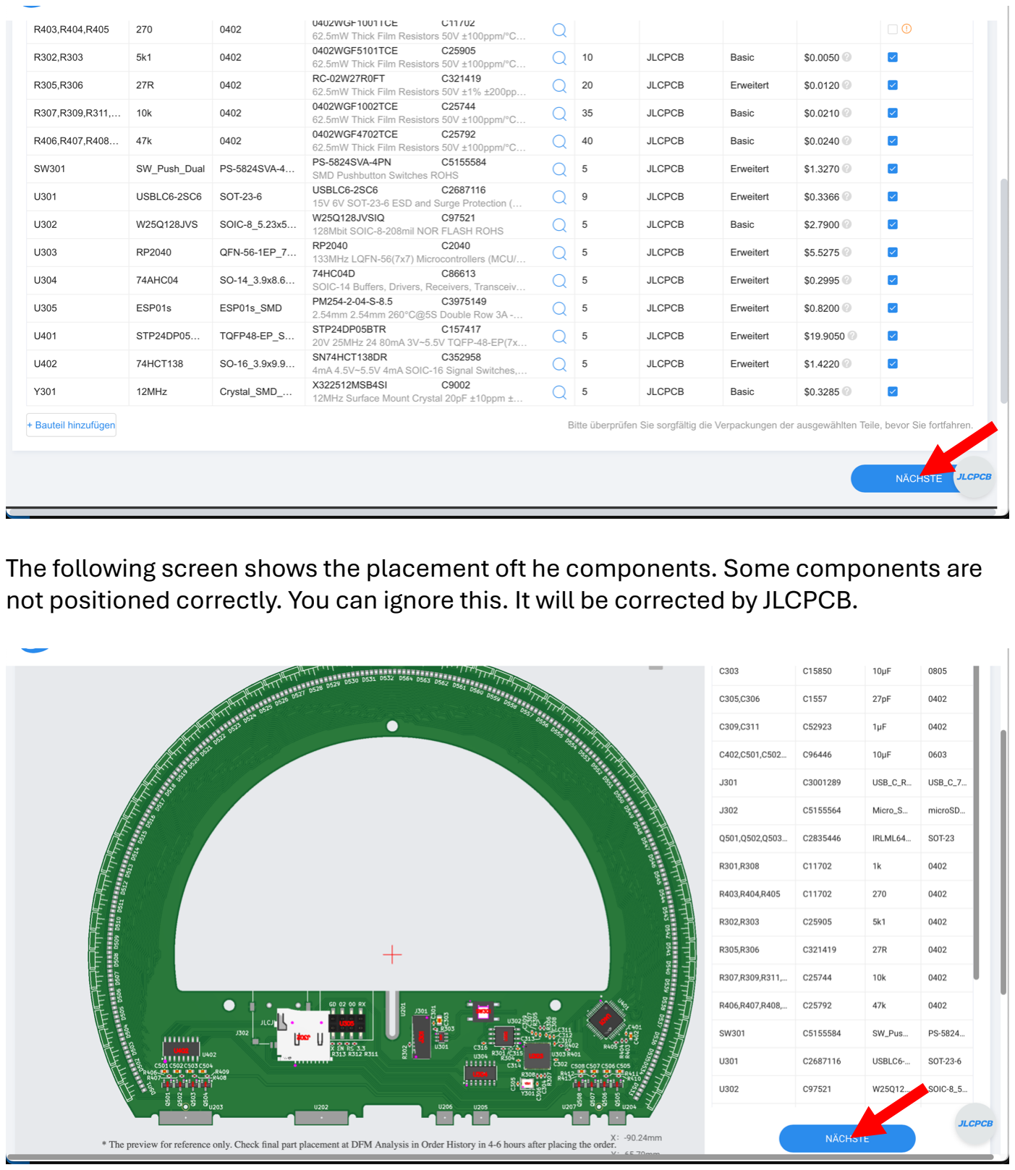
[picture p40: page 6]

The following screen shows the placement oft he components. Some components are not positioned correctly. You can ignore this. It will be corrected by JLCPCB.

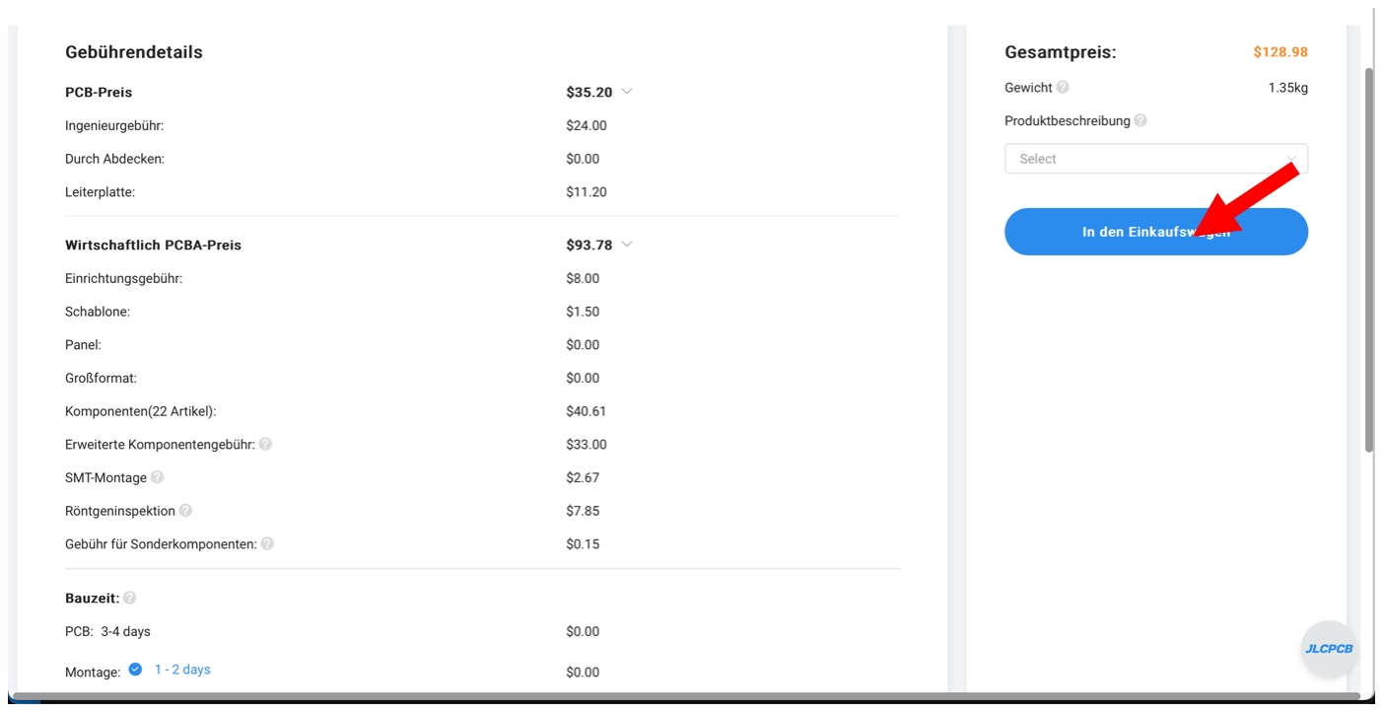
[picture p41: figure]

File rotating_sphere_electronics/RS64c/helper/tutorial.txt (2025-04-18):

https://www.youtube.com/watch?v=KpV5xP95Z70

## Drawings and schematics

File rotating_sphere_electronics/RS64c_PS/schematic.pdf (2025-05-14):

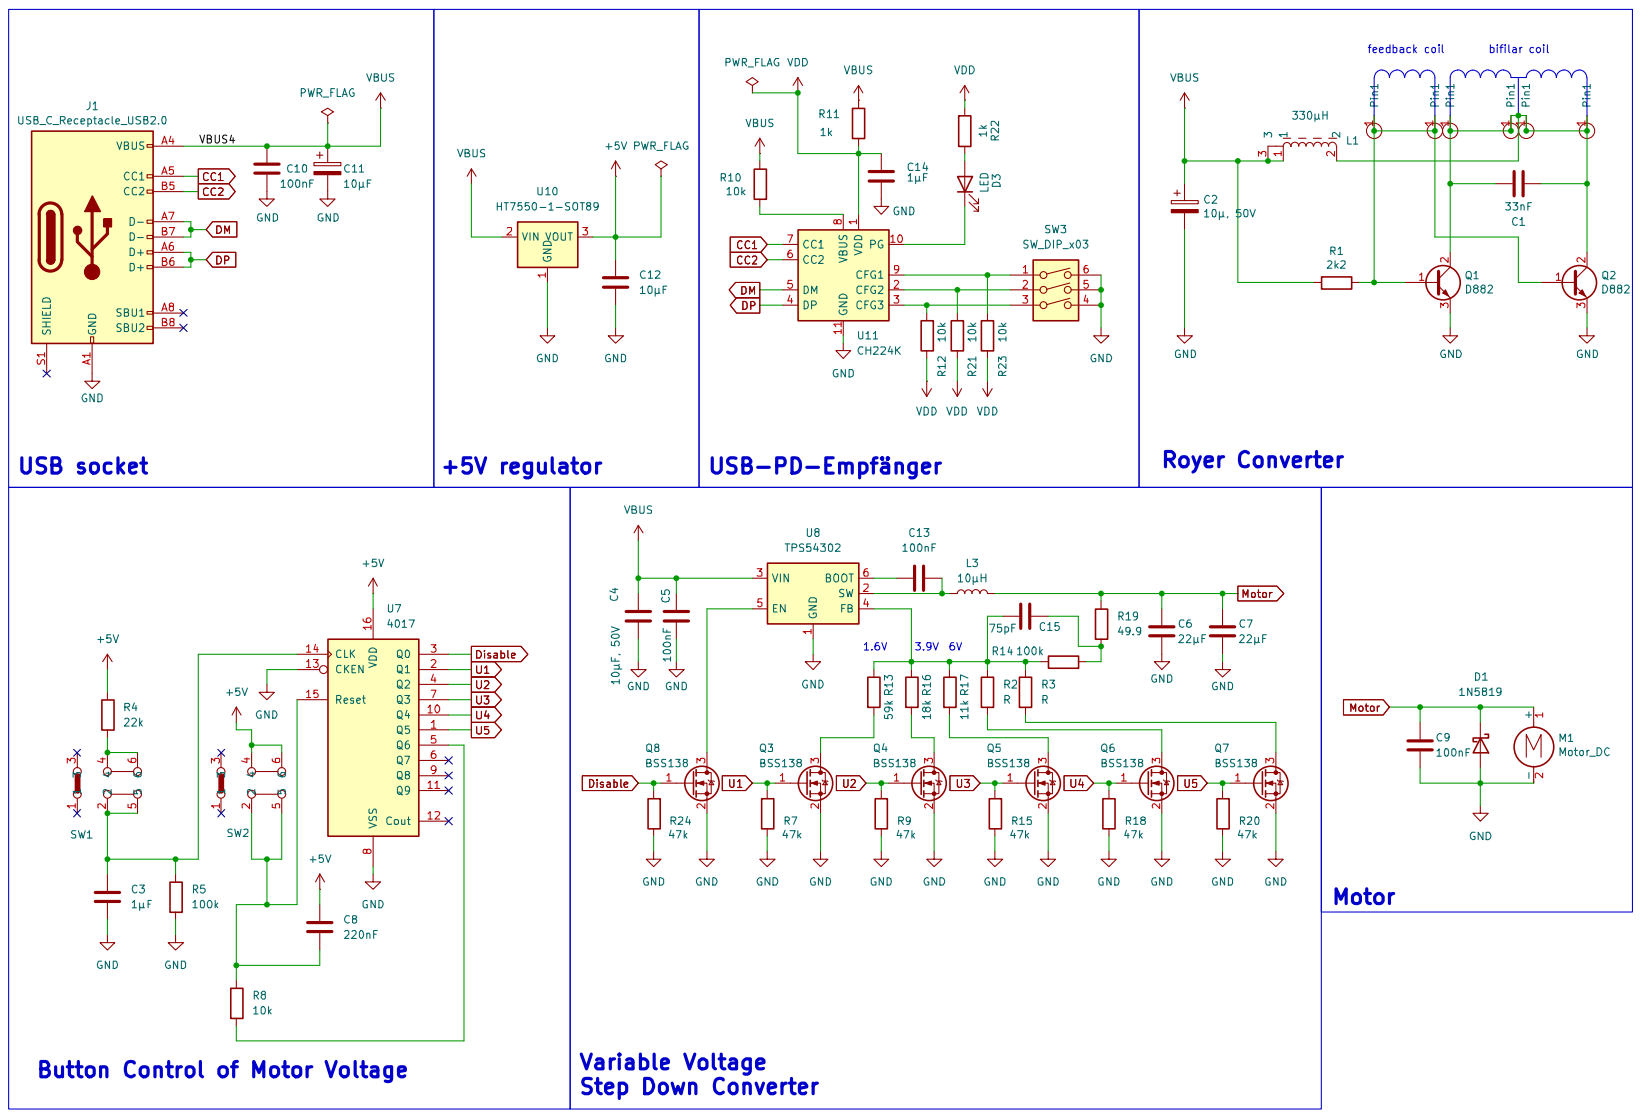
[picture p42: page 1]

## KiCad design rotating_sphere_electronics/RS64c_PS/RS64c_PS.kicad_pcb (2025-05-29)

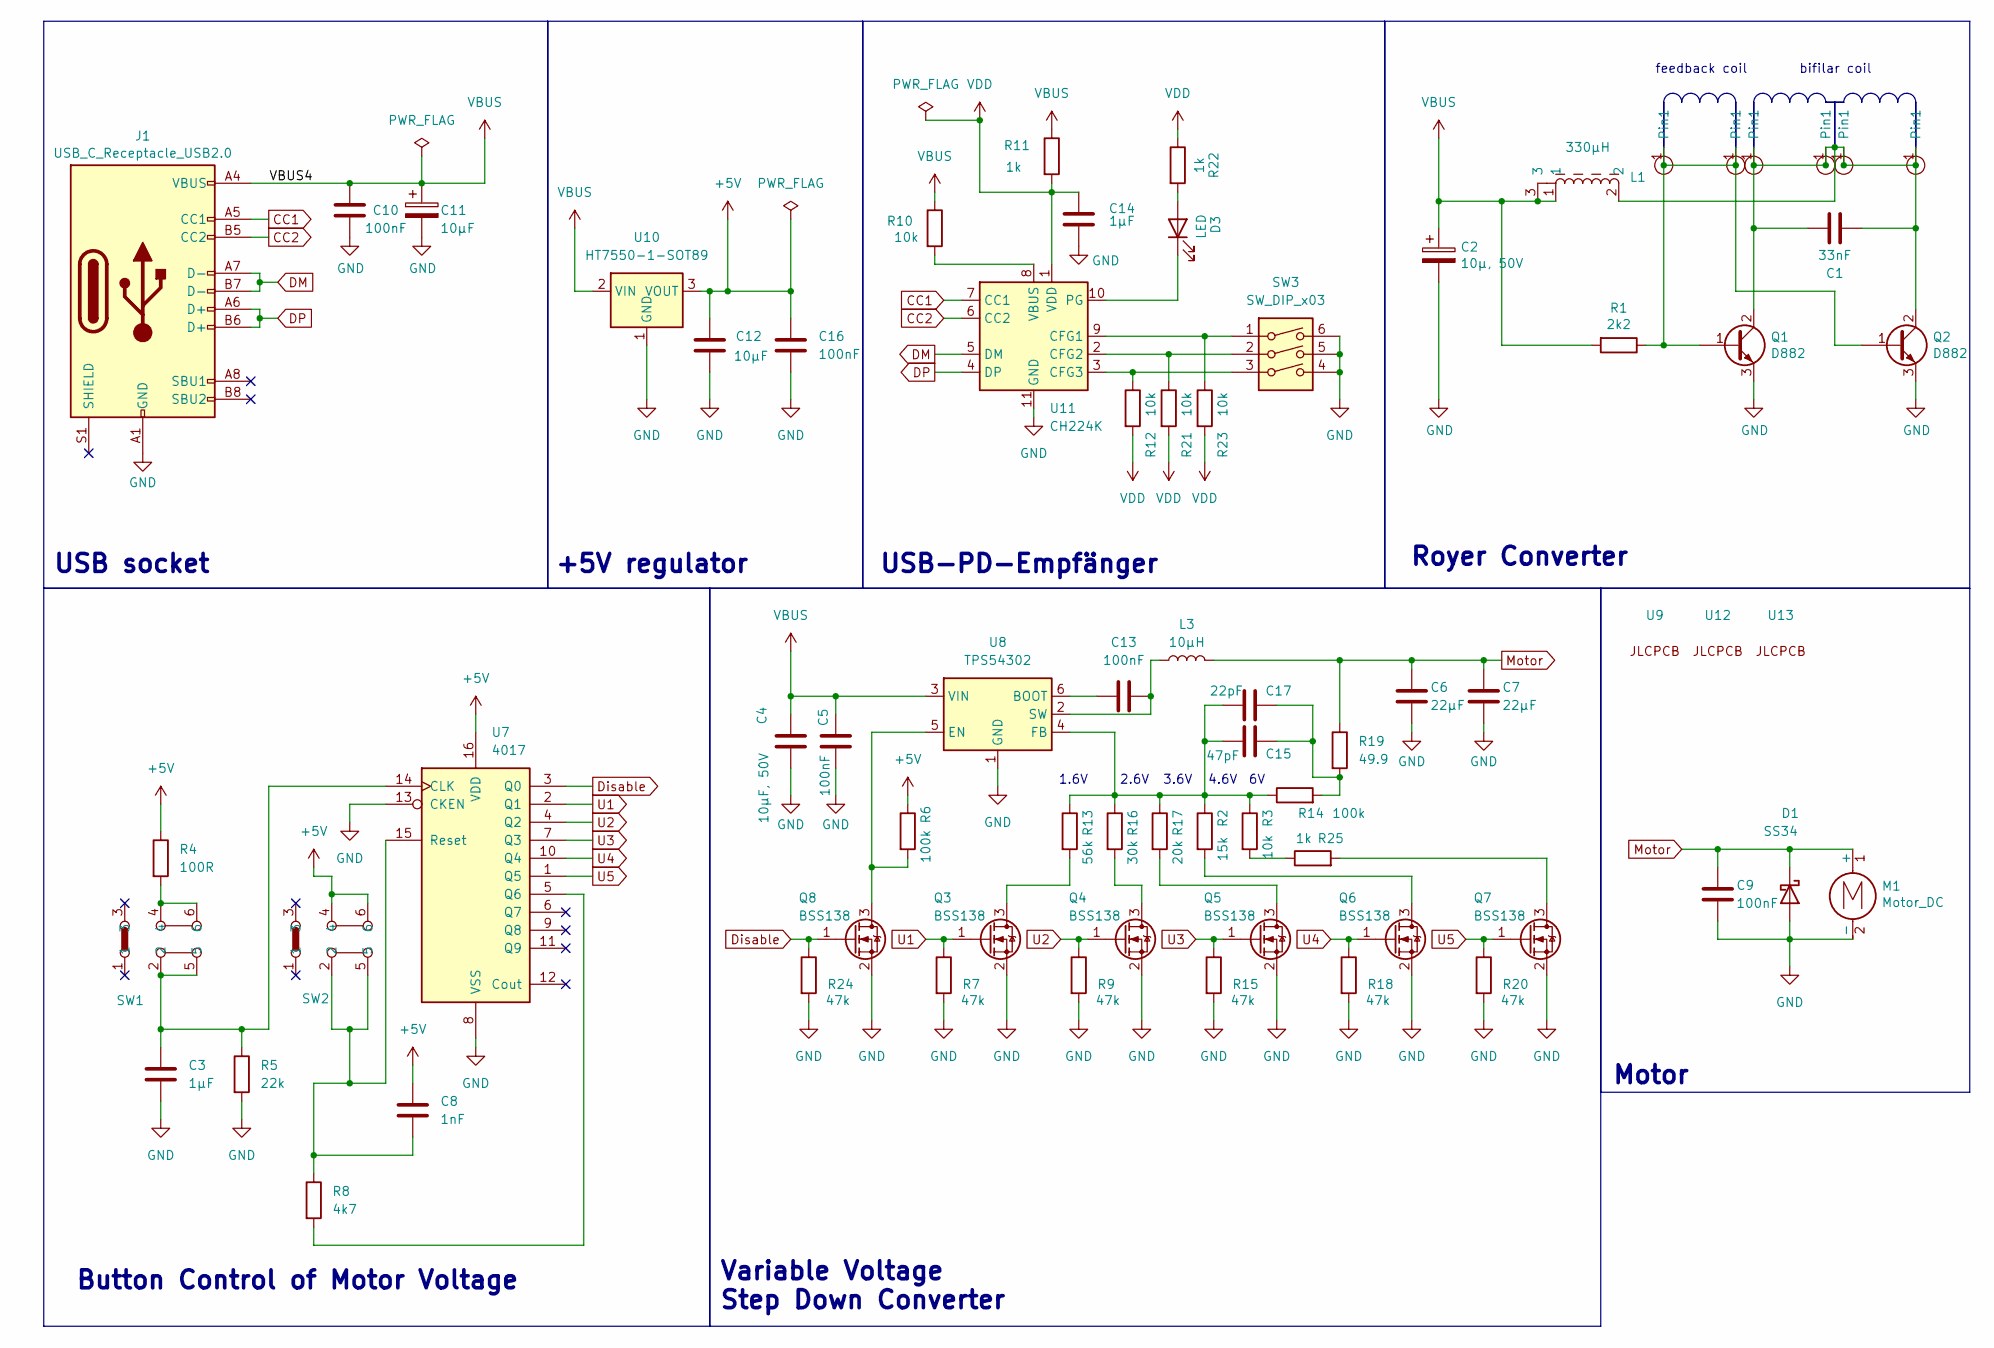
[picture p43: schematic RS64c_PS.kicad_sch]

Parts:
C1: 33nF; C_1812_4532Metric; LCSC C97977
C2: 10µ, 50V; C_1206_3216Metric; LCSC C13585
C3, C14: 1µF; C_0603_1608Metric; LCSC C15849
C4: 10µF, 50V; C_1206_3216Metric; LCSC C13585
C5, C9, C13, C16: 100nF; C_0603_1608Metric; LCSC C14663
C6, C7: 22µF; C_0805_2012Metric; LCSC C45783
C8: 1nF; C_0402_1005Metric; LCSC C1523
C10: 100nF; C_0402_1005Metric; LCSC C307331
C11: 10µF; C_0805_2012Metric; LCSC C440198
C12: 10µF; C_1206_3216Metric; LCSC C13585
C15: 47pF; C_0603_1608Metric; LCSC C1671
C17: 22pF; C_0603_1608Metric; LCSC C1653
D1: SS34; DIOM7959X265N; LCSC C8678
D3: LED; LED_0805_2012Metric; LCSC C84256
J1: USB_C_Receptacle_USB2.0; USB_C_Receptacle; LCSC C709357
L1: 330µH; L_SXN_SMDRI127; LCSC C10152
L3: 10µH; L_Bourns_SRP7028A_7.3x6.6mm; LCSC C5189958
M1: Motor_DC; motor
Q1, Q2: D882; LCSC C9634
Q3, Q4, Q5, Q6, Q7, Q8: BSS138; SOT-23; LCSC C7420339
R1: 2k2; R_0603_1608Metric; LCSC C4190
R2: 15k; R_0402_1005Metric; LCSC C25756
R3, R10, R12, R21, R23: 10k; R_0402_1005Metric; LCSC C25744
R4: 100R; R_0402_1005Metric; LCSC C25076
R5: 22k; R_0402_1005Metric; LCSC C25768
R6, R14: 100k; R_0402_1005Metric; LCSC C25741
R7, R9, R15, R18, R20, R24: 47k; R_0402_1005Metric; LCSC C25792
R8: 4k7; R_0402_1005Metric; LCSC C25900
R11, R25: 1k; R_0402_1005Metric; LCSC C11702
R13: 56k; R_0603_1608Metric; LCSC C23206
R16: 30k; R_0603_1608Metric; LCSC C22984
R17: 20k; R_0402_1005Metric; LCSC C25765
R19: 49.9; R_0402_1005Metric; LCSC C25120
R22: 1k; R_0603_1608Metric; LCSC C21190
SW1, SW2: XKB5858-X-F-75; LCSC C780037
SW3: SW_DIP_x03; SW_DIP_SPSTx03_Slide_9.78x9.8mm_W8.61mm_P2.54mm; LCSC C7421520
U1, U2, U3, U4, U5, U6: Pin-Connector; Pin_2mm
U7: 4017; SOP-16_3.9x9.9mm_P1.27mm; LCSC C22390236
U8: TPS54302; SOT-23-6; LCSC C311983
U9, U12, U13: JLC_tooling_hole
U10: HT7550-1-SOT89; SOT-89-3; LCSC C16106
U11: CH224K; SSOP-10-1EP_3.9x4.9mm_P1mm_EP2.1x3.3mm; LCSC C970725

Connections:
+5V: C8.1, C12.1, C16.1, R4.1, R6.1, SW2.4, SW2.6, U7.16 (VDD), U10.3 (VOUT)
CC1: J1.A5 (CC1), U11.7 (CC1)
CC2: J1.B5 (CC2), U11.6 (CC2)
DM: J1.A7 (D-), J1.B7 (D-), U11.5 (DM)
DP: J1.A6 (D+), J1.B6 (D+), U11.4 (DP)
Disable: Q8.1 (G), R24.1, U7.3 (Q0)
GND: C2.2, C3.2, C4.2, C5.2, C6.2, C7.2, C9.2, C10.1, C11.2, C12.2, C14.2, C16.2, D1.2 (A), J1.A1 (GND), J1.A12 (GND), J1.B1 (GND), J1.B12 (GND), M1.2 (-), Q1.3 (E), Q2.3 (E), Q3.2 (S), Q4.2 (S), Q5.2 (S), Q6.2 (S), Q7.2 (S), Q8.2 (S), R5.2, R7.2, R9.2, R15.2, R18.2, R20.2, R24.2, SW3.4, SW3.5, SW3.6, U7.8 (VSS), U7.13 (CKEN), U8.1 (GND), U10.1 (GND), U11.11 (GND)
Motor: C6.1, C7.1, C9.1, D1.1 (K), L3.2, M1.1 (+), R19.1
unnamed: C15.2, C17.2, R14.2, R19.2
unnamed: D3.2 (A), R22.2
unnamed: D3.1 (K), U11.10 (PG)
unnamed: Q1.1 (B), Q2.1 (B), R1.1, U1.1 (Pin1), U2.1 (Pin1)
unnamed: C1.1, C1.2, L1.2, Q1.2 (C), Q2.2 (C), U3.1 (Pin1), U4.1 (Pin1), U5.1 (Pin1), U6.1 (Pin1)
unnamed: Q3.3 (D), R13.2
unnamed: Q4.3 (D), R16.2
unnamed: Q5.3 (D), R17.2
unnamed: Q6.3 (D), R2.2
unnamed: Q7.3 (D), R25.2
unnamed: Q8.3 (D), R6.2, U8.5 (EN)
unnamed: R4.2, SW1.4, SW1.6
unnamed: R3.2, R25.1
unnamed: C3.1, R5.1, SW1.2, SW1.5, U7.14 (CLK)
unnamed: R8.2, U7.5 (Q6)
unnamed: C8.2, R8.1, SW2.2, SW2.5, U7.15 (Reset)
unnamed: C13.1, U8.6 (BOOT)
unnamed: C15.1, C17.1, R2.1, R3.1, R13.1, R14.1, R16.1, R17.1, U8.4 (FB)
unnamed: C13.2, L3.1, U8.2 (SW)
unnamed: R23.1, SW3.1, U11.9 (CFG1)
unnamed: R21.1, SW3.2, U11.2 (CFG2)
unnamed: R12.1, SW3.3, U11.3 (CFG3)
unnamed: R10.2, U11.8 (VBUS)
U1: Q3.1 (G), R7.1, U7.2 (Q1)
U2: Q4.1 (G), R9.1, U7.4 (Q2)
U3: Q5.1 (G), R15.1, U7.7 (Q3)
U4: Q6.1 (G), R18.1, U7.10 (Q4)
U5: Q7.1 (G), R20.1, U7.1 (Q5)
VBUS: C2.1, C4.1, C5.1, C10.2, C11.1, J1.A4 (VBUS), J1.A9 (VBUS), J1.B4 (VBUS), J1.B9 (VBUS), L1.1, L1.3, R1.2, R10.1, R11.1, U8.3 (VIN), U10.2 (VIN)
VDD: C14.1, R11.2, R12.2, R21.2, R22.1, R23.2, U11.1 (VDD)

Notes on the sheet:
+5V regulator
3.6V
Motor
Royer Converter
feedback coil
4.6V
USB-PD-Empfänger
Variable Voltage Step Down Converter
USB socket
1.6V
bifilar coil
2.6V
Button Control of Motor Voltage

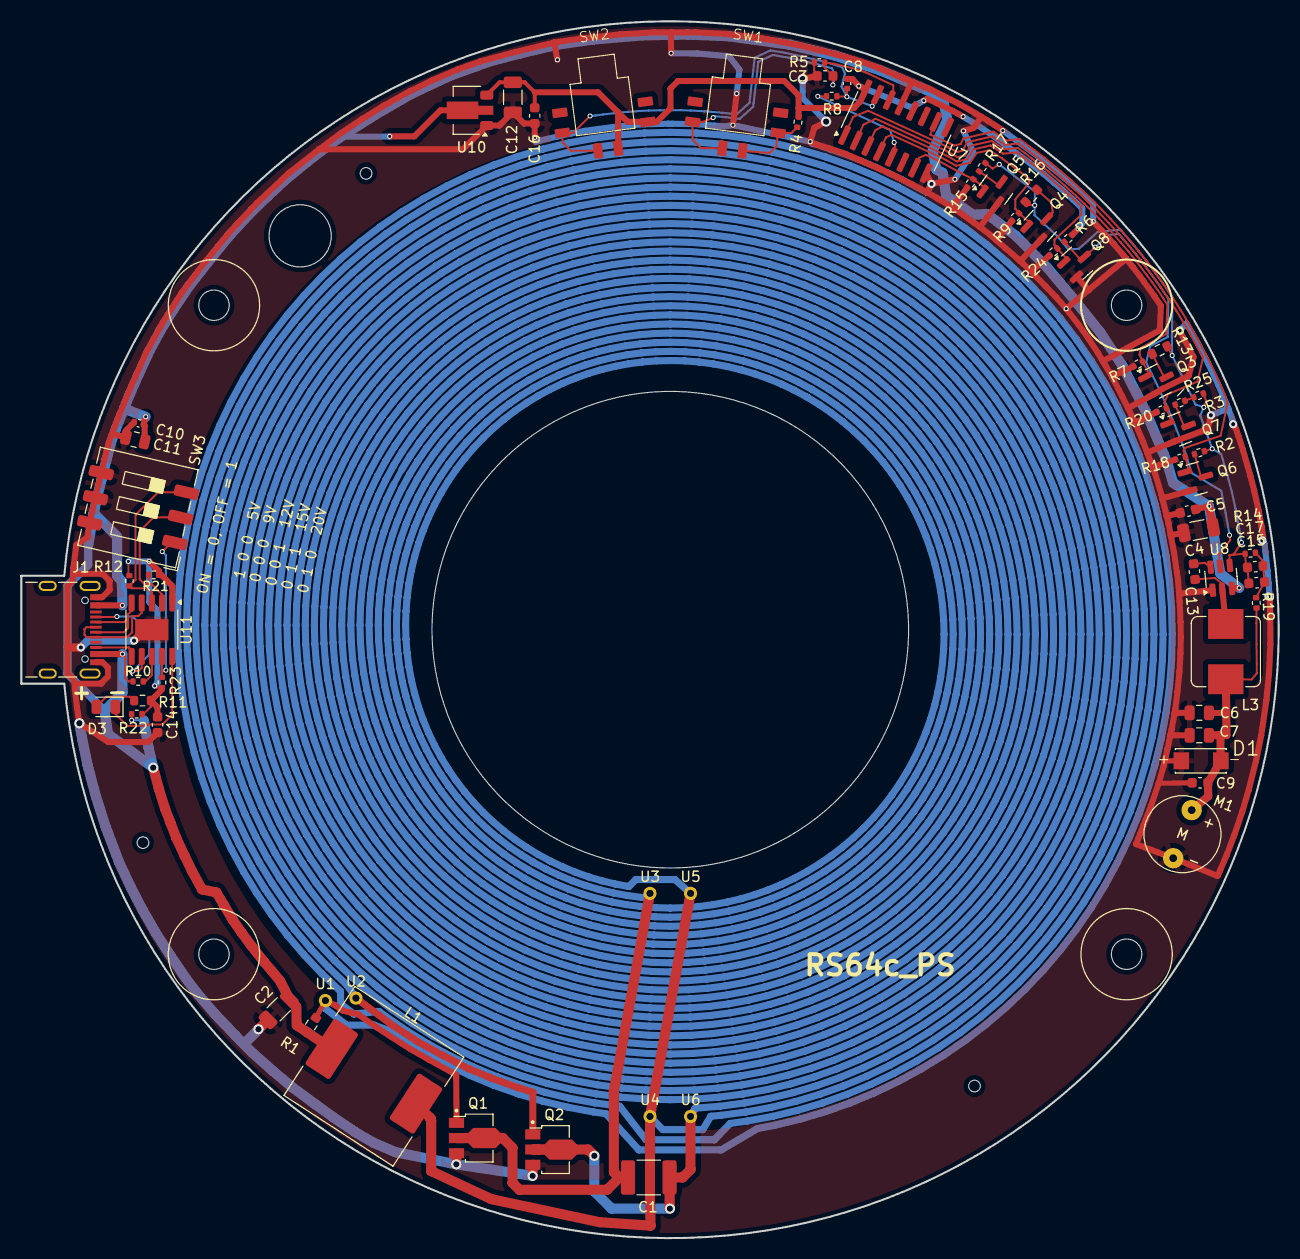
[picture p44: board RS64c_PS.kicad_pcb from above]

Board: 2 copper layers, 124.0 x 120.0 mm, 72 parts (0 on the bottom side), 38 nets.

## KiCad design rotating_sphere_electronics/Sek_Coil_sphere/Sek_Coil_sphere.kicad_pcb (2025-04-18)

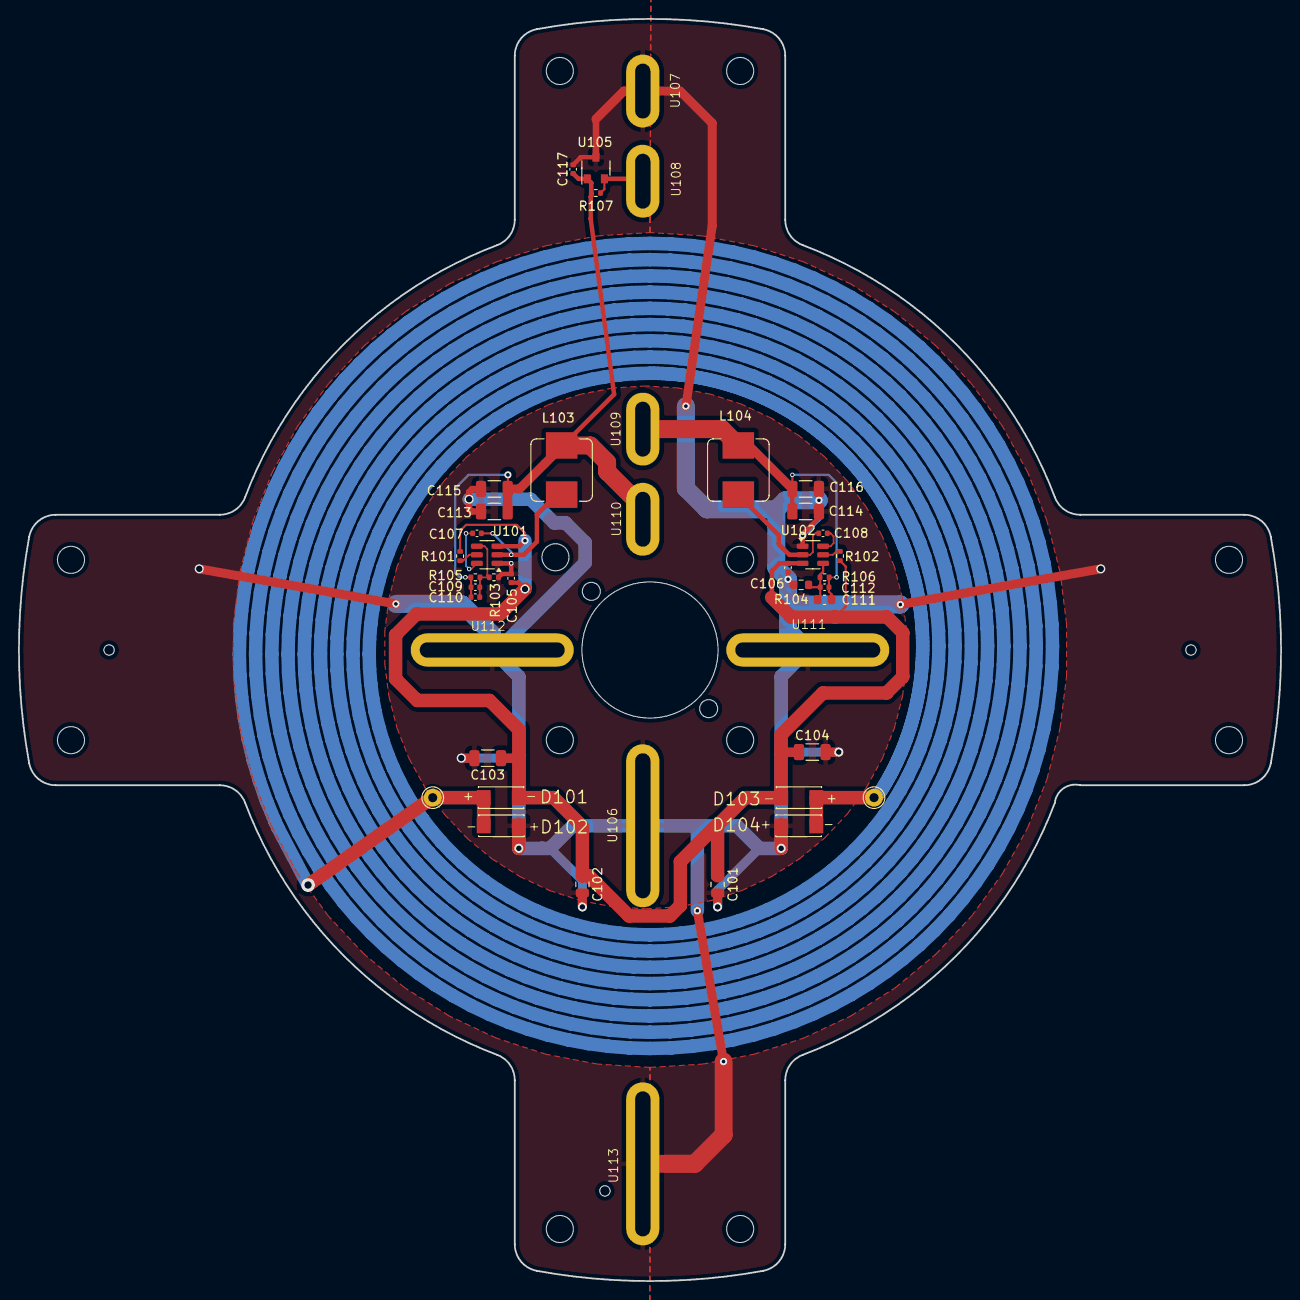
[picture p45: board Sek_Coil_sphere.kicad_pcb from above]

Board: 2 copper layers, 140.0 x 140.0 mm, 43 parts (0 on the bottom side), 14 nets.

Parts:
C101, C102: 22µF, 25V; C_0805_2012Metric
C103, C104: 10µF, 50V; C_1206_3216Metric
C105, C106, C107, C108, C117: 100nF; C_0402_1005Metric
C109, C112: 47pF; C_0402_1005Metric
C110: 10pF; C_0402_1005Metric
C111: 30pF; C_0603_1608Metric
C113, C114, C115, C116: 22µF, 25V; C_1206_3216Metric
D101, D102, D103, D104: SS34; DIOM7959X265N
L103, L104: 33µH; L_Bourns_SRP7028A_7.3x6.6mm
R101, R102, R105, R106: 100k; R_0402_1005Metric
R103: 22k; R_0402_1005Metric
R104: 13k; R_0603_1608Metric
R107: 20k; R_0402_1005Metric
U101, U102: TPS54202DDC; SOT-23-6
U103, U104: Pin_D1.0mm
U105: MH253
U106, U111, U112, U113: slot_long
U107, U108, U109, U110: slot_short

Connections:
+3.3V: C109.1, C110.1, C113.1, C115.1, C117.1, L103.2, R105.2, R107.1, U105.1 (Vcc), U110.1
+5V: C111.1, C112.1, C114.1, C116.1, L104.2, R106.2, U109.1
/EN_BC1: R101.2, U101.5 (EN)
/EN_BC2: R102.2, U102.5 (EN)
/FB_BC1: C109.2, C110.2, R103.2, R105.1, U101.4 (FB)
/FB_BC2: C111.2, C112.2, R104.2, R106.1, U102.4 (FB)
/SW_BC1: C107.2, L103.1, U101.2 (SW)
/SW_BC2: C108.2, L104.1, U102.2 (SW)
/U_unreg: C101.1, C102.1, C103.1, C104.1, C105.1, C106.1, D101.1 (K), D103.1 (K), R101.1, R102.1, U101.3 (VIN), U102.3 (VIN)
/boot_BC1: C107.1, U101.6 (BOOT)
/boot_BC2: C108.1, U102.6 (BOOT)
/coil1: D101.2 (A), D102.1 (K), D103.2 (A), D104.1 (K), U103.1 (pin), U104.1 (pin)
GND: C101.2, C102.2, C103.2, C104.2, C105.2, C106.2, C113.2, C114.2, C115.2, C116.2, C117.2, D102.2 (A), D104.2 (A), R103.1, R104.1, U101.1 (GND), U102.1 (GND), U105.3 (Ground), U106.1, U107.1, U111.1, U112.1, U113.1
unnamed: R107.2, U105.2 (Output), U108.1

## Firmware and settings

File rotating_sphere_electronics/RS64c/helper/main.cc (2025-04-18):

#include "lib.h"
#include <stdio.h>
#include <cmath>
#include <fstream>

double beta(double x, double y);
double radius(double x, double y);
double x_rad(double b, double r);
double y_rad(double b, double r);
void draw_arc(double beta_s, double beta_e, double r, int net);
void draw_line(double xs, double ys, double xe, double ye, int net, std::string layer);
void draw_via(double x, double y, int net);
void draw_via_g(double x, double y);                   // draw ground via at x, y

double LED_x(int LED_nr, int pin);
double LED_y(int LED_nr, int pin);

double rule_here(double b);
void generate_edges();
void add_edge(double b);
void sort_edges();
void occupy_rad();
void fix_mini();
int compare_desc(const void *a, const void *b);
void print_edges();

void add_obst(double beta_start, double beta_end, double r);
void add_obst_via(double vx, double vy);
void add_obst_arc(double abs, double abe, double ar);

void draw_line_05(double xs, double ys, double xe, double ye, int net, std::string layer);
void draw_arc_05(double beta_s, double beta_e, double r, int net);

std::ofstream f;
std::string line1;

double rules_beta_start[60000];
double rules_beta_end[60000];
double rules_rad[60000];
int rules_nr=0;
double edge_seq[10000];
int edge_nr=0;
double rad_seq[10000];

int main() {
    printer("LED data\n");

    std::string file_name = "/Users/ludwin/Elektronik/rotating_sphere/rotating_sphere_electronics/RS64c/helper/output.txt";
    f.open(file_name);

// =======================================================
// 8er Anodenleitungen

    double b_start = beta(-76.3, 55);
    int lookup1[] = {19, 42, 43, 44, 48, 47, 46, 45};

    for (int gruppe=0; gruppe<4; gruppe++) {
        double schraeg = 0.4;
        double an_r = 79.5 + (double)gruppe * 0.41;
        double b_end = beta(LED_x((gruppe*8+7), 2), LED_y((gruppe*8+7), 2))+ schraeg/an_r;
        draw_arc(b_start, b_end, an_r, lookup1[gruppe]);
        for (int g_led=0; g_led<8; g_led++) {
            int LED = g_led+gruppe*8;
            double  t_b = beta(LED_x(LED,2), LED_y(LED,2));
            double t_r = an_r;
            double z_b = t_b+schraeg/t_r;
            draw_line( LED_x(LED, 2), LED_y(LED, 2), x_rad(t_b, t_r-schraeg),y_rad(t_b, t_r-schraeg), lookup1[gruppe], "F.Cu");
            draw_line( x_rad(t_b, t_r-0.4),y_rad(t_b, t_r-0.4), x_rad(z_b, t_r),y_rad(z_b, t_r), lookup1[gruppe], "F.Cu");
        }
    }

    for (int gruppe=4; gruppe<8; gruppe++) {
        double schraeg = 0.4;
        double an_r = 79.5 + (7.0-(double)gruppe) * 0.41;
        double b_end = beta(LED_x((gruppe*8), 2), LED_y((gruppe*8), 2))- schraeg/an_r;
        draw_arc(-b_start, b_end, an_r, lookup1[gruppe]);
        for (int g_led=0; g_led<8; g_led++) {
            int LED = g_led+gruppe*8;
            double  t_b = beta(LED_x(LED,2), LED_y(LED,2));
            double t_r = an_r;
            double z_b = t_b-schraeg/t_r;
            draw_line( LED_x(LED, 2), LED_y(LED, 2), x_rad(t_b, t_r-schraeg),y_rad(t_b, t_r-schraeg), lookup1[gruppe], "F.Cu");
            draw_line( x_rad(t_b, t_r-0.4),y_rad(t_b, t_r-0.4), x_rad(z_b, t_r),y_rad(z_b, t_r), lookup1[gruppe], "F.Cu");
        }
    }

// 24 Kathodenringe
//
    int lookup2[]={17, 18, 20,  23, 22, 21,  24, 26, 25,  27, 28, 29,    32, 30, 31,  34, 35, 33,  37, 38, 36,  41, 40, 39};
    double kr0_r = 76.2;
    int pins_left[]={3, 4, 1};
    int pins_right[]={1, 4, 3};

    rules_beta_start[0]=b_start+20/kr0_r;
    rules_beta_end[0]=-rules_beta_start[0];
    rules_rad[0]=kr0_r;
    rules_nr=1;

    generate_edges();
    print_edges();

    for (int kr=0; kr<24; kr++) {

        if (kr==0) {
            draw_arc(b_start, -b_start, kr0_r, lookup2[kr]);  // obstacle list ist bereits initialisiert
        }
        else {

            // ==============================
            // zeichne Bogen mit Hindernis-Unterbrechnungen
            for (int index = 0; index<edge_nr-1; index++) {
                double bs = edge_seq[index];
                double be = edge_seq[index+1];
                double rs = rad_seq[index]-0.43;
                double re = rad_seq[index+1]-0.43;
                if ((rs!=re)||(bs!=be)) {
                    draw_arc(bs, be, rs, lookup2[kr]);
                    draw_line(x_rad(be, rs), y_rad(be, rs), x_rad(be, re), y_rad(be, re), lookup2[kr], "F.Cu");
                    add_obst(bs, be, rs);
                }
                if (re!=rs) {
                    double kl = re;
                    if (rs<re) kl=rs;
                    add_obst(be+0.41/rs, be-0.41/rs, kl);
                }
            }

            generate_edges();
            print_edges();
        }

        for (int gruppe=0; gruppe<8; gruppe++) {                    // <8 !!
            int led_index = kr/3;
            int pin_index = kr%3;
            if (gruppe>3) led_index = 7-led_index;
            int LED_N = gruppe*8+led_index;
            printer ("gruppe: "+std::to_string(gruppe)+"   led_index: "+std::to_string(led_index)+"   LED_N: "+std::to_string(LED_N)+"\n");
            int pin_N;
            if (kr<12) pin_N=pins_left[pin_index];
            else pin_N=pins_right[pin_index];

            double pinx = LED_x(LED_N, pin_N);
            double piny = LED_y(LED_N, pin_N);
            double pin_beta = beta(pinx, piny);

            draw_via_g(x_rad(pin_beta+0.62/84, 78.-1.21), y_rad(pin_beta+0.62/84, 78.-1.21));

            if (kr==0) {
                draw_line(pinx, piny, x_rad(pin_beta, kr0_r-0.41*kr), y_rad(pin_beta, kr0_r-0.41*kr), lookup2[kr], "F.Cu");
            }
            if (kr>0) {
                double r_via = rule_here(pin_beta)-0.15;
                draw_line(pinx, piny, x_rad(pin_beta, r_via), y_rad(pin_beta, r_via), lookup2[kr], "B.Cu");
                draw_via(x_rad(pin_beta, r_via), y_rad(pin_beta, r_via), lookup2[kr]);
                add_obst_via(x_rad(pin_beta, r_via), y_rad(pin_beta, r_via));
                double vg_b = pin_beta+0.65/r_via;
                double vg_r = rule_here(vg_b)-0.16;
                double dx=x_rad(pin_beta, r_via)-x_rad(vg_b, vg_r);
                double dy=y_rad(pin_beta, r_via)-y_rad(vg_b, vg_r);
                double dist = sqrt(dx*dx+dy*dy);
                if ((dist)>0.7) {
                    vg_r=r_via-0.3;
                    vg_b=pin_beta;
                }
                draw_via_g(x_rad(vg_b, vg_r-0.42), y_rad(vg_b, vg_r-0.42));
                add_obst_via(x_rad(vg_b, vg_r-0.42), y_rad(vg_b, vg_r-0.42));
            }
        }
        generate_edges();
        print_edges();


    }


    f.close();

    return 0;
}


// =======================================================

double beta(double x, double y) {
    double pi = 3.14159265359;
    double beta = atan(x/y);
    if ((x<0)&&(y>0)) beta = pi+beta;
    if ((x>0)&&(y>0)) beta = beta-pi;
    return beta;
}

double radius(double x, double y) {
    double radi = sqrt(x*x+y*y);
    return radi;
}

double x_rad(double b, double r) {
    double x_r = -r * sin(b);
    return x_r;
}

double y_rad(double b, double r) {
    double y_r = -r * cos(b);
    return y_r;
}

void draw_arc(double beta_s, double beta_e, double r, int net) {
    double pi = 3.14159265359;
    double delta_arc = 10/(2*pi*62);
    int max;
    if (beta_e<beta_s) {
        max = (int)((beta_s-beta_e)/delta_arc);
    } else {
        max = (int)(-(beta_s-beta_e)/delta_arc);
        delta_arc=-delta_arc;
    }
    double start_x = x_rad(beta_s, r);
    double start_y = y_rad(beta_s, r);
    double end_x, end_y;

    for (int i=1; i<max; i++) {
        end_x = x_rad(beta_s-i*delta_arc, r);
        end_y = y_rad(beta_s-i*delta_arc, r);
        if ((start_x!=end_x)||(start_y!=end_y)) draw_line (start_x, start_y, end_x, end_y, net, "F.Cu");
        start_x = end_x;
        start_y = end_y;
    }
    if ((start_x != x_rad(beta_e, r))||(start_y!=y_rad(beta_e, r)))draw_line (start_x, start_y, x_rad(beta_e, r), y_rad(beta_e, r), net, "F.Cu");
}

void draw_arc_05(double beta_s, double beta_e, double r, int net) {
    double pi = 3.14159265359;
    double delta_arc = 6/(2*pi*62);
    int max;
    if (beta_e<beta_s) {
        max = (int)((beta_s-beta_e)/delta_arc);
    } else {
        max = (int)(-(beta_s-beta_e)/delta_arc);
        delta_arc=-delta_arc;
    }
    double start_x = x_rad(beta_s, r);
    double start_y = y_rad(beta_s, r);
    double end_x, end_y;

    for (int i=1; i<max; i++) {
        end_x = x_rad(beta_s-i*delta_arc, r);
        end_y = y_rad(beta_s-i*delta_arc, r);
        draw_line_05 (start_x, start_y, end_x, end_y, net, "F.Cu");
        start_x = end_x;
        start_y = end_y;
    }
    draw_line_05 (start_x, start_y, x_rad(beta_e, r), y_rad(beta_e, r), net, "F.Cu");
}

void draw_line(double xs, double ys, double xe, double ye, int net, std::string layer) {
    line1 ="(segment (start "+std::to_string(xs)+" "+std::to_string(ys)+") (end "+std::to_string(xe)+" "+std::to_string(ye)+") (width 0.2) (layer """+layer+""") (net "+std::to_string(net)+") (uuid ""17aabb6f-34a1-466f-abac-eb0441075269""))\n";
    if ((xs!=xe)||(ys!=ye)) f<<line1;
}

void draw_line_05(double xs, double ys, double xe, double ye, int net, std::string layer) {
    line1 ="(segment (start "+std::to_string(xs)+" "+std::to_string(ys)+") (end "+std::to_string(xe)+" "+std::to_string(ye)+") (width 0.5) (layer """+layer+""") (net "+std::to_string(net)+") (uuid ""17aabb6f-34a1-466f-abac-eb0441075269""))\n";
    f<<line1;
}


void draw_via(double x, double y, int net) {
    line1 ="(via (at "+std::to_string(x)+" "+std::to_string(y)+") (size 0.5) (drill 0.3) (layers ""F.Cu"" ""B.Cu"") (free yes) (net "+std::to_string(net)+") (uuid ""17aabb6f-34a1-466f-abac-eb0441075269""))\n";
    f<<line1;
}

void draw_via_g(double x, double y) {
    line1 ="(via (at "+std::to_string(x)+" "+std::to_string(y)+") (size 0.5) (drill 0.3) (layers ""F.Cu"" ""B.Cu"") (free yes) (net 2) (uuid ""17aabb6f-34a1-466f-abac-eb0441075269""))\n";
    f<<line1;
}


double LED_x(int LED_nr, int pin) {
    if (LED_nr>31) pin = 5-pin;
    double width = 5.5;
    double rLED = 84.0;
    double be = (width/4 + width * (31-LED_nr))/rLED;
    double rk = 78.0;
    double y = -((double)pin - 2.5)*1.27;
    double rs = sqrt(y*y+rk*rk);
    double delta = atan(y/rk);
    double bs = be-delta;
    return x_rad(bs, rs);
}

double LED_y(int LED_nr, int pin) {
    if (LED_nr>31) pin = 5-pin;
    double width = 5.5;
    double rLED = 84.0;
    double be = (width/4 + width * (31-LED_nr))/rLED;
    double rk = 78.0;
    double y = -((double)pin - 2.5)*1.27;
    double rs = sqrt(y*y+rk*rk);
    double delta = atan(y/rk);
    double bs = be-delta;
    return y_rad(bs, rs);
}



double rule_here(double b) {          // gibt den Radius zurück, der bei b gilt
    double here = 80.;
    for (int i=0; i<rules_nr; i++) {
        if ((rules_beta_start[i]>=b)&&(rules_beta_end[i]<=b)) {
            if (rules_rad[i]<here) here=rules_rad[i];
        }
    }
    return here;
}

void add_obst(double beta_start, double beta_end, double r) {
//    printer ("add_obst: beta_start"+std::to_string(beta_start)+"  beta_end: "+std::to_string(beta_end) + "  r: " + std::to_string(r)+"  rules_nr: "+std::to_string(rules_nr)+"\n");
    rules_beta_start[rules_nr]=beta_start;
    rules_beta_end[rules_nr]=beta_end;
    rules_rad[rules_nr]=r;
    rules_nr++;
}

void generate_edges() {
    edge_nr=0;
    for (int i = 0; i<rules_nr; i++) {
        add_edge(rules_beta_start[i]);
        add_edge(rules_beta_end[i]);
    }
    sort_edges();
    occupy_rad();
    fix_mini();
}

void add_edge(double b) {
    bool does_exist=false;
    for (int k=0; k<edge_nr; k++) {
        if (edge_seq[k]==b) does_exist=true;
    }
    if (does_exist==false) {
        edge_seq[edge_nr]=b;
        edge_nr++;
    }
}

void sort_edges() {
    qsort(edge_seq, (size_t)edge_nr, sizeof(double), compare_desc);
}

void occupy_rad() {
    for (int i = 0; i<edge_nr; i++) {
        double mid;
        if (i!=edge_nr-1) {
            mid = (edge_seq[i]+edge_seq[i+1])/2;
        } else {
            mid = edge_seq[i];
        }
        rad_seq[i]=rule_here(mid);
    }
}

void fix_mini() {
    for (int i = 1; i<edge_nr-20; i++) {
        if (rad_seq[i]>rad_seq[i-1]) {
            int k=0;
            for (k=1; k<20;k++) {
                if (rad_seq[i+k]<rad_seq[i]) break;
            }
            if (k<20) {
                if (fabs(edge_seq[i]-edge_seq[i+k])<4.0/rad_seq[i]) {
                    for (int m=0; m<k; m++) rad_seq[i+m]=rad_seq[i-1];
                }
            }

        }
    }
}

int compare_desc(const void *a, const void *b) {
    double da = *(const double*)a;
    double db = *(const double*)b;
    return (db > da) - (db < da); // Umgekehrte Reihenfolge
}

void add_obst_via(double vx, double vy) {
    double vb = beta(vx, vy);
    double vr = radius(vx, vy);
    double vb1 = vb+0.57/vr;
    double vb2 = vb-0.57/vr;
    double vr1 = vr-0.135;
    add_obst(vb1, vb2, vr1);
}


void add_obst_arc(double abs, double abe, double ar) {
    add_obst(abs, abe, ar-0.12);
}

void print_edges() {
    for(int m=0; m<edge_nr; m++) {
        printer("aufsteigend >>> edge_nr: "+std::to_string(m)+"   edge_seq: "+std::to_string(edge_seq[m])+"\n");

    }
}

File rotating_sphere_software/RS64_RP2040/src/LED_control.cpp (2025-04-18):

// =========================================================================================================================================
//                                                 Rotating Display RS64c
//                                                    © Ludwin Monz
// License: Creative Commons Attribution - Non-Commercial - Share Alike (CC BY-NC-SA)
// you may use, adapt, share. If you share, "share alike".
// you may not use this software for commercial purposes 
// =========================================================================================================================================

#include "LED_control.h"
#include "globals.h"
#include <Arduino.h>

// Definition of static variables
uint64_t LED_control::_timePerTurn = 0;
uint32_t LED_control::_timePerLine= 30000;
uint32_t LED_control::_lineCounter = 0;              // 0....1791
uint32_t LED_control::_lineOffset = lineOffset;
uint8_t LED_control::lines[8][1792][3] = {0};	     // 8 bytes with 8 LEDs each, 1792 subpixel lines, 3 colors
uint32_t LED_control::brightness = 0x100;
PIO LED_control::pio = pio1;                         // SdFat uses pio0 
uint LED_control::sm0 = 0;
uint LED_control::sm1 = 1;


// =========================================================================================================================================
//                                                      Constructor
// =========================================================================================================================================

LED_control::LED_control() {
}

// =========================================================================================================================================
//                                                      begin Method
// =========================================================================================================================================

void LED_control::begin() {
    _initMultiplexer();
    _initHallIRQ();
    _initPixelIRQ();
}

void LED_control::_initMultiplexer(){

    // Load LED_multiplexer_sm0 and LED_multiplexer_sm1 into this PIO's instruction memory.
    uint offset0 = pio_add_program(pio, &LED_multiplexer_sm0_program);
    uint offset1 = pio_add_program(pio, &LED_multiplexer_sm1_program);

    // initiate confic structures c0 and c1
    pio_sm_config c0 = LED_multiplexer_sm0_program_get_default_config(offset0);
    pio_sm_config c1 = LED_multiplexer_sm1_program_get_default_config(offset1);

    // Map the sm0 OUT pin group to pins 4, 5, 6, 7 (row selection lines)
    sm_config_set_out_pins(&c0, 4, 4);
    // map the sm0 SET pins to pin 2, 3 (LE and OE)
    sm_config_set_set_pins(&c0, 2, 2);
    // Map the sm1 OUT pin group to pins 0 (data)
    sm_config_set_out_pins(&c1, 0, 1); 
    // map the sm1 SET pins to pin 1 (clock)
    sm_config_set_set_pins(&c1, 1, 1);


    // define status
    sm_config_set_mov_status (&c1, STATUS_TX_LESSTHAN , 1 );   

    // Join TX FIFO sm0 (2x4 32 bit words = 8 32 bit words)
    sm_config_set_fifo_join	(&c0, PIO_FIFO_JOIN_TX);	
    // Join TX FIFO sm1
    sm_config_set_fifo_join	(&c1, PIO_FIFO_JOIN_TX);	
   
    // Set pindir for all pins
    pio_sm_set_consecutive_pindirs(pio, sm0, 2, 6, true);
    // Set pindir for all pins
    pio_sm_set_consecutive_pindirs(pio, sm1, 0, 2, true);
   
    // set clk frequency to 130/5 MHz = 26 MHz. 
    sm_config_set_clkdiv_int_frac(&c0, 1, 0);  // 
    sm_config_set_clkdiv_int_frac(&c1, 1, 0);  // 

    // enable IRQ by setting IRQ0_INTE - interrupt enable register    pis_interrupt0 = PIO_INTR_SM0_LSB
    // this routes the PIO SM interrupts (IRQ0...IRQ7) to the system interrupts 7 and 8.
    pio_set_irq0_source_enabled(pio, pis_interrupt0 , true);
    //Set the handler in the NVIC. IRQ7 = PIO0_IRQ_0
    irq_set_exclusive_handler(7, _pioIRQ);  
    //enabling the PIO0_IRQ_0
    irq_set_enabled(7, true);   

    // Set this pin's GPIO function "pio"
    for (uint i=0; i<8; i++) pio_gpio_init(pio, i);

    // Load configuration to pio, and jump to the start of the program
    pio_sm_init(pio, sm0, offset0, &c0);
    pio_sm_init(pio, sm1, offset1, &c1);

    // Set the state machine running
    pio_sm_set_enabled(pio, sm0, true);
    pio_sm_set_enabled(pio, sm1, true);
}

void LED_control::_pioIRQ() {               // not needed in RS64, as 64 LEDs data can be stored at once in the FIFO
    pio_interrupt_clear(pio, 0);                               // clear interrupt
}

void LED_control::_initHallIRQ() {
    gpio_init(Hall);
    gpio_set_dir(Hall, GPIO_IN);
    gpio_set_function(Hall, GPIO_FUNC_SIO);								// software IO control (SIO)

	gpio_set_irq_enabled_with_callback(Hall, GPIO_IRQ_EDGE_FALL, true, &_HallIRQ);    // attach HallRIQ

    pwm_clear_irq(0);										// clear pwm interrupt
    pwm_set_irq_enabled(0, true);							// enable pwm interrupt

} 

void LED_control::_HallIRQ(uint gpio, uint32_t events) {
    _timePerTurn = _timePerTurn + pwm_get_counter(0);

	uint64_t newTimePerLine = _timePerTurn/1792;

	if (newTimePerLine>65500) newTimePerLine = 65500;

    uint64_t delta = labs(newTimePerLine - _timePerLine);
    if(delta<10) _timePerLine = (63*_timePerLine+newTimePerLine)/64;      // Otherwise make small corrections, only.
  	if((delta>=10)&&(delta<100)) _timePerLine = (15*_timePerLine+newTimePerLine)/16;
    if(delta>=100) _timePerLine = newTimePerLine;
    
    pwm_set_wrap (0, _timePerLine);							// upper threshold of counter 2
    pwm_clear_irq(0);										// clear pwm interrupt

 	_timePerTurn = 0;                             
  	_lineCounter = _lineOffset;  							// restart line_counter
    _lineCounter = _lineCounter%1792;
    _fillFifo();
}

void LED_control::_initPixelIRQ() {
    gpio_init(PWM0_A);										// set gpio as output
    gpio_set_dir(PWM0_A, true);								//

    gpio_set_function(PWM0_A, GPIO_FUNC_PWM);				// enable PWM pin

    pwm_set_wrap (2, _timePerLine);							// upper threshold of counter 0
    pwm_set_phase_correct (0, false);						// counter 0 will reset to 0, once upper threshold is reached

    pwm_set_clkdiv_int_frac(0, 1, 0);					    // set divisor for clock divider (system clock = 125 MHz)

    pwm_set_chan_level(0, 0, _timePerLine-1);			    // level is the mid threshold, when the output goes to zero

    pwm_set_enabled (0, true);								// enable PWM slice 0 (output pins 16 and 17)

    irq_set_exclusive_handler(PWM_IRQ_WRAP, _PixelIRQ);		// attach PixelIRQ() to the PWM interrupt
    irq_set_enabled(PWM_IRQ_WRAP, true);					// enanble irq

	_startPattern();
}

void LED_control::_PixelIRQ() {    
    _timePerTurn+=_timePerLine;

    _lineCounter++;
    _lineCounter = _lineCounter%1792;


    _fillFifo();
	pwm_clear_irq(0);										// clear interrupt
}
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

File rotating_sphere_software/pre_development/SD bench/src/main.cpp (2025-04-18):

#include <Arduino.h>


//=============================================
// RP2040 PIO SDIO setup and test.
/*
This example requires a SDIO Card socket with the following six lines.

CLK - A clock signal sent to the card by the MCU.
CMD - A bidirectional line for for commands and responses.
DAT[0:3] - Four bidirectional lines for data transfer.

CLK and CMD can be connected to any GPIO pins. DAT[0:3] can be connected
to any four consecutive GPIO pins in the order DAT0, DAT1, DAT2, DAT3.

For testing, I use several RP2040/RP3350 boards.
The Adafruit Metro RP2040 which has a builtin SDIO socket.

https://learn.adafruit.com/adafruit-metro-rp2040

I use this SD socket breakout board for other boards.

https://learn.adafruit.com/adafruit-microsd-spi-sdio

Wires should be short since signals can be as faster than 50 MHz.
*/
#define DISABLE_FS_H_WARNING  // Disable warning for type File not defined.
#include "SdFat.h"
#include "FreeStack.h"
#include "sdios.h"

#define SDIO 1 // 0 => use SPI, 1 => use SDIO

#if SDIO == 1  // ==== use SDIO interface =====
#define RP_CLK_GPIO 20
#define RP_CMD_GPIO 19
#define RP_DAT0_GPIO 15
#define SD_CONFIG SdioConfig(RP_CLK_GPIO, RP_CMD_GPIO, RP_DAT0_GPIO)

#elif SDIO == 0  // ==== use SPI interface ====
const uint8_t SD_CS_PIN = 17;
#define SD_CONFIG SdSpiConfig(SD_CS_PIN, DEDICATED_SPI, SPI_CLOCK)
//=============================================
// Try max SPI clock for an SD. Reduce SPI_CLOCK if errors occur.
#define SPI_CLOCK SD_SCK_MHZ(50)

#endif

//------------------------------------------------------------------------------
// Class File is not defined by SdFat since the RP2040 system defines it.
// use type 3: FAT16/FAT32 and exFAT.

SdFs sd;
FsFile file;


//=============================================
// Set PRE_ALLOCATE true to pre-allocate file clusters.
const bool PRE_ALLOCATE = true;

// Set SKIP_FIRST_LATENCY true if the first read/write to the SD can
// be avoid by writing a file header or reading the first record.
const bool SKIP_FIRST_LATENCY = true;

// Size of read/write.
const size_t BUF_SIZE = 512;

// File size in MB where MB = 1,000,000 bytes.
const uint32_t FILE_SIZE_MB = 5;

// Write pass count.
const uint8_t WRITE_COUNT = 2;

// Read pass count.
const uint8_t READ_COUNT = 2;

// File size in bytes.
const uint32_t FILE_SIZE = 1000000UL * FILE_SIZE_MB;

// Insure 4-byte alignment.
uint32_t buf32[(BUF_SIZE + 3) / 4];
uint8_t* buf = (uint8_t*)buf32;

// Serial output stream
ArduinoOutStream cout(Serial);
//------------------------------------------------------------------------------
// Store error strings in flash to save RAM.
#define error(s) sd.errorHalt(&Serial, F(s))
//------------------------------------------------------------------------------
void cidDmp() {
  cid_t cid;
  if (!sd.card()->readCID(&cid)) {
    error("readCID failed");
  }
  cout << F("\nManufacturer ID: ");
  cout << uppercase << showbase << hex << int(cid.mid) << dec << endl;
  cout << F("OEM ID: ") << cid.oid[0] << cid.oid[1] << endl;
  cout << F("Product: ");
  for (uint8_t i = 0; i < 5; i++) {
    cout << cid.pnm[i];
  }
  cout << F("\nRevision: ") << cid.prvN() << '.' << cid.prvM() << endl;
  cout << F("Serial number: ") << hex << cid.psn() << dec << endl;
  cout << F("Manufacturing date: ");
  cout << cid.mdtMonth() << '/' << cid.mdtYear() << endl;
  cout << endl;
}
//------------------------------------------------------------------------------
void clearSerialInput() {
  uint32_t m = micros();
  do {
    if (Serial.read() >= 0) {
      m = micros();
    }
  } while (micros() - m < 10000);
}
//------------------------------------------------------------------------------



void setup() {
  Serial.begin(9600);

  // Wait for USB Serial
  while (!Serial) {
    yield();
  }
  delay(1000);
  cout << F("\nUse a freshly formatted SD for best performance.\n");

  if (!ENABLE_DEDICATED_SPI) {
    cout << F(
        "\nSet ENABLE_DEDICATED_SPI nonzero in\n"
        "SdFatConfig.h for best SPI performance.\n");
  }
  if (!SD_HAS_CUSTOM_SPI && !USE_SPI_ARRAY_TRANSFER && isSpi(SD_CONFIG)) {
    cout << F(
          "\nSetting USE_SPI_ARRAY_TRANSFER nonzero in\n"
          "SdFatConfig.h may improve SPI performance.\n");
  }
  // use uppercase in hex and use 0X base prefix
  cout << uppercase << showbase << endl;

}

void loop() {
    float s;
  uint32_t t;
  uint32_t maxLatency;
  uint32_t minLatency;
  uint32_t totalLatency;
  bool skipLatency;

  // Discard any input.
  clearSerialInput();

  // F() stores strings in flash to save RAM
  cout << F("Type any character to start\n");
  while (!Serial.available()) {
    yield();
  }
#if HAS_UNUSED_STACK
  cout << F("FreeStack: ") << FreeStack() << endl;
#endif  // HAS_UNUSED_STACK

  if (!sd.begin(SD_CONFIG)) {
    sd.initErrorHalt(&Serial);
  }
  if (sd.fatType() == FAT_TYPE_EXFAT) {
    cout << F("Type is exFAT") << endl;
  } else {
    cout << F("Type is FAT") << int(sd.fatType()) << endl;
  }

  cout << F("Card size: ") << sd.card()->sectorCount() * 512E-9;
  cout << F(" GB (GB = 1E9 bytes)") << endl;

  cidDmp();

  // open or create file - truncate existing file.
  if (!file.open("bench.dat", O_RDWR | O_CREAT | O_TRUNC)) {
    error("open failed");
  }

  // fill buf with known data
  if (BUF_SIZE > 1) {
    for (size_t i = 0; i < (BUF_SIZE - 2); i++) {
      buf[i] = 'A' + (i % 26);
    }
    buf[BUF_SIZE - 2] = '\r';
  }
  buf[BUF_SIZE - 1] = '\n';

  cout << F("FILE_SIZE_MB = ") << FILE_SIZE_MB << endl;
  cout << F("BUF_SIZE = ") << BUF_SIZE << F(" bytes\n");
  cout << F("Starting write test, please wait.") << endl << endl;
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

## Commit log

2025-04-18 BOM added
    [BOM.xlsx]
2025-04-28 deleted bom.csv and positions.csv in the production files
    [BOM.xlsx, bom.csv, positions.csv]
2025-04-28 how to order PCBs from JLCPCB
2025-04-30 R403, 404, 405 corrected
    [LED_electronics.kicad_sch, bom.xlsx, positions.xlsx]
2025-04-30 more testing results in readme.md on the 270 Ohm brightness resistors
2025-05-04 BOM updated
2025-05-14 new PS design complete
    [RS64c_PS.kicad_pcb, RS64c_PS.kicad_sch, RS64c_PS.sch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]
2025-05-29 new PS design released, readme.md updated
    [RD56c_PS_V1.kicad_pcb, RD56c_PS_V1.kicad_sch, RS64c_PS.kicad_pcb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]
2025-08-29 update of readme, new stl files for power supply base
    [USB_C_PS2_base.stl, USB_C_PS2_clamp.stl, USB_C_PS2_housing.stl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]
2025-12-24 print instructions added. readme.md updated
    [rotating_sphere.3mf, sphere_PS1_USB_C v6.stl]
2026-02-09 added some photos
    [Basis v1.f3d, Basis v1.stl]

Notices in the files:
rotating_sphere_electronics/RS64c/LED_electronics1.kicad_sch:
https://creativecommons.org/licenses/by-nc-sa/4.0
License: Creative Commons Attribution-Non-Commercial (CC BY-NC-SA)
